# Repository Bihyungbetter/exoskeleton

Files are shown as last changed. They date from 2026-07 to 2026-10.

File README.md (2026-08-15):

# Exoskeleton 

## Overview

Exoskeleton is a powered lower-limb exoskeleton with six actuated joints — hip flexion, hip abduction, and knee flexion per leg. Each joint is driven by a CubeMars AK-series actuator (AK70-10 / AK80-64) commanded over CAN by a Teensy 4.1 running through a custom dual-CAN power distribution board, which supplies six independent motor power outputs. The frame — waist, hip abductors, hip-to-thigh, thigh-to-knee, and knee-to-shank sections — is designed in SolidWorks; the electronics are designed in KiCad.

## Features

- Six actuated joints (hip flexion, hip abduction, knee) via CubeMars AK70-10 / AK80-64 actuators
- Custom power distribution board: XT90 main input, 6× XT30 motor power outputs (one per actuator), 50A MIDI fuse, dump resistor, thermal switch input, and battery voltage sense
- Dual CAN bus (CAN A / CAN B, SN65HVD230 transceivers) for actuator communication
- Teensy 4.1 as the main controller
- Modular frame: waist (left/middle/right), hip abductors, hip-to-waist and hip-to-thigh frames, thigh-to-knee frames, knee-to-shank frames, and hip/knee step-up and step-down joint hardware

## Repository layout

- `SolidWorks Assembly/July 2026/July 2026 Exo Assembly/` — SolidWorks parts and the top-level assembly (`Pitt Exo - Final July 2026 Assembly.SLDASM`)
- `pcb/` — KiCad project for the power distribution / control board (schematic, PCB layout, fabrication outputs)
- `pcb/production/` — BOM, designators, placement data, IPC netlist, and Gerber/drill ZIP for fabrication
- `Digikey Order`, `Exoskeleton-JLCPCB Assembly Order (1).xls` — component and assembly ordering records

## Bill of materials

The authoritative electrical BOM is [`pcb/production/bom.csv`](pcb/production/bom.csv). In summary, the power/control board uses:

- 1 Teensy 4.1 controller
- 2 SN65HVD230 CAN transceivers (CAN A / CAN B)
- 1 XT90 power input and 6 XT30 motor power connectors
- 1 50A MIDI fuse, 1 IRFB4110 MOSFET, dump resistor output, thermal switch input, and battery sense header
- Supporting passives (bulk 680 µF caps, TVS/flyback diodes, 120 Ω CAN bus termination)

The mechanical assembly (SolidWorks) is built from 22 parts, including the waist sections, left/right hip abductors, hip-to-waist and hip-to-thigh frames, thigh-to-knee and knee-to-shank frames, hip/knee step-up and step-down joint hardware, and the AK70-10 / AK80-64 motor body and center mounts.

## Pictures



Exoskeleton



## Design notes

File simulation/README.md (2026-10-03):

# exo-sim

MuJoCo simulation of a person wearing a hip/knee exoskeleton (waist, bilateral
hip abduction and flexion, knee), with a PPO policy that drives the exo motors
while the person walks. The exo model comes from our SolidWorks assembly and
the human model is MyoSuite's MyoLeg from MyoAssist.

## Layout

| path | what |
|---|---|
| `controllers/human_baseline.py` | human side: PD hold on the 8 leg joints, per-joint torque caps, trunk (root) hold |
| `controllers/gait.py` | fixed periodic gait for the human's hips and knees |
| `controllers/exo_assistance.py` | exo side: the only code that writes the 6 motor commands; applies rated torque, slew and cuff limits |
| `controllers/safety.py`, `measurements.py`, `wholebody_allocator.py`, `torso_balance.py`, `balance_margin.py` | sensing, safety supervisor, torque allocation |
| `envs/stepping_env.py` | Gymnasium env (plant + human + exo + reward). Walking uses `exo_action=True, gait_drive=True` |
| `envs/plant_setup.py` | drops the feet onto the floor and lines the exo up with the body at reset |
| `scripts/train_stepping_ppo.py` | PPO trainer (Stable-Baselines3), normally run through `tools/train_watchdog.py` |
| `tools/evaluate_walking.py` | scores policies against the control on held-out seeds |
| `tools/view_policy.py` | plays a policy in the MuJoCo viewer |
| `models/human_exo_direct_ak80abd.xml` | plant used for all results below (exo torque applied straight to the human joints, abduction motors sized as AK80-64) |
| `models/human_exo_direct.xml` | same direct plant with the original AK70-10 abduction motors; `SteppingEnv`'s default |
| `models/human_exo.xml` | the real attachment: exo coupled to the body through five compliant cuffs |
| `models/meshes/` | exo meshes from the CAD (visual and collision) |
| `models/walking_decim5_20260916.zip` | trained policy |
| `models/gait_walk_base.json`, `models/exo_transmission_calibration*.json` | gait parameters, exo transmission calibration |
| `runs/` | train, score and view scripts with matching flags |

## Running it

```powershell
runs\run_view_walking_decim5.cmd            # watch the policy (pass "none" for the control)
runs\score_walking_decim5.cmd               # policy vs control on 48 held-out seeds
runs\run_walking_decim5_20260916.cmd        # retrain; ~2 h on 6 workers, overwrites the policy file
```

Setup: Python 3.11, `pip install -r requirements.txt`, and a clone of
[MyoAssist](https://github.com/neumovelab/myoassist) at `third_party/myoassist`.
Only its MyoLeg model files (`myosuite/simhive/myo_sim`) are used, so it doesn't
need to be pip-installed. The model XMLs have absolute paths in them, but
`tools/model_paths.py` rewrites those relative to wherever the repo lives, so a
fresh clone works once MyoAssist is in place.

## Results so far

48 held-out seeds (40000 to 40047), 12 s episodes, exo control running at 200 Hz:

| | falls | distance | exo share of hip+knee torque |
|---|---|---|---|
| control (fixed assist law, offload 0.6) | 32/48 | 1.82 m | 29% |
| trained policy | 0/48 | 3.72 m | 53% |

Most of the gain is in not falling. Human hip/knee torque only drops about 5%
compared with the control, and under the policy at least one motor is pinned at
its 48 N·m limit about half the time.

## Limitations

These numbers don't transfer to a real person yet, for a few reasons.

The trunk is kept upright by a 100 N·m PD torque applied directly to the root
joint, with no reaction on the rest of the body (about 43 N·m on average under
the policy). Without it the model falls over during the settle phase. Relative
comparisons between arms are fine since every arm gets the same hold, but
absolute survival rates aren't meaningful.

The human is torque driven. The MyoLeg model has 80 muscles but none of them
are used, and the human doesn't adapt to the exo: it's a fixed gait on fixed
PD gains. The ankle is held at neutral by a PD spring, so there's no push-off,
and the exo has no ankle motor.

Everything above is on the direct-drive plant. On the cuff model
(`human_exo.xml`) every seed falls: the cuffs only pass about 6 N·m in total, so
fixing the attachment is a mechanical design problem before it's a control one.

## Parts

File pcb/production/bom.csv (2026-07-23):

Designator | Footprint | Quantity | Value | LCSC Part #
_4, _3, _2, |  | 4
C1, C2, C3, C4 | CP_Radial_D18.0mm_P7.50mm | 4 | 680uF 100V
C5 | C_Disc_D7.5mm_W4.4mm_P5.00mm | 1 | 100nF
C6, C9 | 0805 | 2 | 100nF
C7 | 1206 | 1 | 10uF 25V
C8 | 0805 | 1 | 10nF
D1 | D_SMC | 1 | SMCJ58CA
D2 | SOT-23 | 1 | BAT54S
D3 | D_DO-41_SOD81_P10.16mm_Horizontal | 1 | BZX85C12
D4 | LED_D3.0mm | 1 | CHOP_ACTIVE
D5 | D_SMC | 1 | ES3D
F1 | Fuse_MIDI_BF1-58V_50A_BoltDown_2xM6_P30mm | 1 | BF1 58V MIDI 50A (142.7010.5502)
J11 | AMASS_XT30PW-F_1x02_P2.50mm_Horizontal | 1 | PWR M5
J13 | AMASS_XT30PW-F_1x02_P2.50mm_Horizontal | 1 | PWR M6
J15 | PinHeader_1x02_P2.54mm_Vertical | 1 | TERM2
J16 | PinHeader_1x02_P2.54mm_Vertical | 1 | BATT_SENSE
J17 | AMASS_XT30PW-F_1x02_P2.50mm_Horizontal | 1 | DUMP_RESISTOR
J19 | PinHeader_1x02_P2.54mm_Vertical | 1 | THERMAL_SW
J2 | PinHeader_1x02_P2.54mm_Vertical | 1 | TERM
J3 | AMASS_XT30PW-F_1x02_P2.50mm_Horizontal | 1 | PWR M1
J4 | JST_GH_SM02B-GHS-TB_1x02-1MP_P1.25mm_Horizontal | 1 | CANA
J5 | AMASS_XT30PW-F_1x02_P2.50mm_Horizontal | 1 | PWR M2
J6 | JST_GH_SM02B-GHS-TB_1x02-1MP_P1.25mm_Horizontal | 1 | CANB
J7 | AMASS_XT30PW-F_1x02_P2.50mm_Horizontal | 1 | PWR M3
J9 | AMASS_XT30PW-F_1x02_P2.50mm_Horizontal | 1 | PWR M4
Q1 | SOT-23 | 1 | MMBT3906
Q2 | TO-220-3_Vertical | 1 | IRFB4110
R1, R5 | R_Axial_DIN0207_L6.3mm_D2.5mm_P10.16mm_Horizontal | 2 | 120R
R10, R7 | 0805 | 2 | 4.7K
R11 | 0805 | 1 | 5.1K
R12 | 0805 | 1 | 1K
R13, R16, R17, R2, R20, R6 | 0805 | 6 | 10K
R14 | 0805 | 1 | 1M
R15 | 0805 | 1 | 100
R18, R9 | 0805 | 2 | 100K
R19 | 0805 | 1 | 33K
R3 | R_Axial_DIN0207_L6.3mm_D2.5mm_P10.16mm_Horizontal | 1 | 1K
R8 | R_Axial_Power_L20.0mm_W6.4mm_P25.40mm | 1 | 1K 3W
SW1 | SW_Slide_SPDT_Straight_CK_OS102011MS2Q | 1 | SW_SPDT
U1 | Teensy41 | 1 | Teensy4.1
U2, U4 | SOIC-8_3.9x4.9mm_P1.27mm | 2 | SN65HVD230
U3 | TO-92_Inline | 1 | TL431LP
XT90PWRIN1 | AMASS_XT90PW-M_1x02_P10.90mm_Horizontal | 1 | Conn_01x02_Pin

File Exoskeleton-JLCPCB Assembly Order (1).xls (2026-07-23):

JLCPCB BOM Tool - BOM Matching
BOM name：Exoskeleton-JLCPCB Assembly Order.xlsx |  |  | Download Time：2026-07-23 23:40:37 |  |  |  | * Our matching results are updated in real-time, but stock and prices may change. If it's been over 24 hours, please re-match before placing your order.
PCB Assembled Qty：5 |  |  | Est. Total Price：61.8538
Your BOM |  |  |  |  | Matched Parts |  |  |  |  |  |  | Order Information
Top Designator | Bottom Designator | Comment | Footprint | JLCPCB Part # | Matches | Part # | Manufacturer | Footprint | Description | Category | Warning | JLCPCB Part # | Product link | Lib Type | Qty | Source | Total Price ($)
C1,C2,C3,C4 |  | 680uF100V | Capacitor_THT:CP_Radial_D18.0mm_P7.50mm |  | Select by Customer | EEUFC2A681 | PANASONIC | 插件,D18xL40mm | -55℃~+105℃ 100V 18mm 2.3A@100kHz 36mΩ@100kHz 40mm 5000hrs@105℃ 680uF 7.5mm ±20% 插件,D18xL40mm Aluminum Electrolytic Capacitors - Leaded ROHS | Aluminum Electrolytic Capacitors - Leaded |  | C178686 | https://jlcpcb.com/partdetail/PANASONIC-EEUFC2A681/C178686 | Extended | 20 | 20 JLCPCB | 37.028
C5 |  | 100nF | Capacitor_THT:C_Disc_D7.5mm_W4.4mm_P5.00mm |  | Select by Customer | CT4G-0805-2X1-63V-0.1uF-K | TORCH | 插件,P=5.08mm | 100nF 5.08mm 63V ±10% 插件,P=5.08mm Multilayer Ceramic Capacitors MLCC - Leaded ROHS | Multilayer Ceramic Capacitors MLCC - Leaded |  | C400087 | https://jlcpcb.com/partdetail/TORCH-CT4G_0805_2X1_63V_0_1uFK/C400087 | Extended | 9 | 9 JLCPCB | 0.4968
C6,C9 |  | 100nF | Capacitor_SMD:C_0805_2012Metric |  | Select by System | CC0805KRX7R9BB104 | YAGEO | 0805 | 100nF 50V X7R ±10% 0805 Multilayer Ceramic Capacitors MLCC - SMD/SMT ROHS | Multilayer Ceramic Capacitors MLCC - SMD/SMT |  | C49678 | https://jlcpcb.com/partdetail/YAGEO-CC0805KRX7R9BB104/C49678 | Basic | 20 | 20 JLCPCB | 0.642
C7 |  | 10uF25V | Capacitor_SMD:C_1206_3216Metric |  | Select by System | CL31A106KBHNNNE | Samsung Electro-Mechanics | 1206 | 10uF 50V X5R ±10% 1206 Multilayer Ceramic Capacitors MLCC - SMD/SMT ROHS | Multilayer Ceramic Capacitors MLCC - SMD/SMT |  | C13585 | https://jlcpcb.com/partdetail/14236-CL31A106KBHNNNE/C13585 | Basic | 9 | 9 JLCPCB | 4.0725
C8 |  | 10nF | Capacitor_SMD:C_0805_2012Metric |  | Select by System | CL21B103KBANNNC | Samsung Electro-Mechanics | 0805 | 10nF 50V X7R ±10% 0805 Multilayer Ceramic Capacitors MLCC - SMD/SMT ROHS | Multilayer Ceramic Capacitors MLCC - SMD/SMT |  | C1710 | https://jlcpcb.com/partdetail/2062-CL21B103KBANNNC/C1710 | Basic | 20 | 20 JLCPCB | 0.378
D1 |  | SMCJ58CA | Diode_SMD:D_SMC |  | Select by System | SMCJ58CA | DOWO | SMC(DO-214AB) | -55℃~+150℃ 1.5kW@10/1000us 16.03A 1uA 58V 64.4V 93.6V Bidirectional IEC 61000-4-2 TVS SMC(DO-214AB) ESD and Surge Protection (TVS/ESD) ROHS | ESD And Surge Protection (TVS/ESD) |  | C2887185 | https://jlcpcb.com/partdetail/DOWO-SMCJ58CA/C2887185 | Extended | 6 | 6 JLCPCB | 0.591
D2 |  | BAT54S | Package_TO_SOT_SMD:SOT-23 |  | Select by System | BAT54S | hongjiacheng | SOT-23 | 1 Pair Series Connection 200mA 2uA@30V 30V 400mV@10mA 600mA SOT-23 Schottky Diodes ROHS | Schottky Diodes |  | C7420333 | https://jlcpcb.com/partdetail/hongjiacheng-BAT54S/C7420333 | Extended | 10 | 10 JLCPCB | 0.151
D3 |  | BZX85C12 | Diode_THT:D_DO-41_SOD81_P10.16mm_Horizontal |  | Select by System | BZX85C12 | onsemi | DO-41 | -65℃~+200℃ 1 Independent 11.4V~12.7V 12V 1W 350Ω 500nA@8.4V 9Ω DO-41 Zener Diodes ROHS | Zener Diodes |  | C890279 | https://jlcpcb.com/partdetail/onsemi-BZX85C12/C890279 | Extended | 7 | 7 JLCPCB | 0.7518
D4 |  | CHOP_ACTIVE | LED_THT:LED_D3.0mm |  | Select by Customer | 204-10SDRD/S530-A3-L | Everlight Elec | 插件,D=3mm | -40℃~+85℃ 1.7V~2.4V 20mA 3mm Round Lens 40mcd~80mcd 50° 639nm 650nm Discrete Diode Frosted Red Lens Red 插件,D=3mm LED Indication - Discrete ROHS | LED Indication - Discrete |  | C84774 | https://jlcpcb.com/partdetail/EverlightElec-204_10SDRD_S530_A3L/C84774 | Extended | 7 | 7 JLCPCB | 0.2352
D5 |  | ES3D | Diode_SMD:D_SMC |  | Select by System | ES3D | YFW | SMB | -55℃~+150℃ 1 Independent 200V 35ns 3A 5uA@200V 90A 950mV@3A SMB Fast Recovery / High Efficiency Diodes ROHS | Fast Recovery / High Efficiency Diodes |  | C2898336 | https://jlcpcb.com/partdetail/YFW-ES3D/C2898336 | Extended | 9 | 9 JLCPCB | 0.3501
J4 |  | CANA | Connector_JST:JST_GH_SM02B-GHS-TB_1x02-1MP_P1.25mm_Horizontal |  | Select by Customer | SM02B-GHS-TB(LF)(SN) | JST | SMD,P=1.25mm,卧贴 | -25℃~+85℃ 1 1.25mm 1A 1x2P 2 2P 4.13mm 4.25mm 5.75mm 50V Auxiliary Solder Pin GH PA9T Phosphor bronze Surface Mount, Right Angle Tin UL94V-0 White SMD,P=1.25mm,卧贴 Wire To Board Connector ROHS | Wire To Board Connector | 1.Multiple lines in the BOM have been matched to the same part. Please check if the matching is correct. ; | C189893 | https://jlcpcb.com/partdetail/JST-SM02B_GHS_TB_LF_SN/C189893 | Extended | 12 | 12 JLCPCB | 2.298
J6 |  | CANB | Connector_JST:JST_GH_SM02B-GHS-TB_1x02-1MP_P1.25mm_Horizontal |  | Select by Customer | SM02B-GHS-TB(LF)(SN) | JST | SMD,P=1.25mm,卧贴 | -25℃~+85℃ 1 1.25mm 1A 1x2P 2 2P 4.13mm 4.25mm 5.75mm 50V Auxiliary Solder Pin GH PA9T Phosphor bronze Surface Mount, Right Angle Tin UL94V-0 White SMD,P=1.25mm,卧贴 Wire To Board Connector ROHS | Wire To Board Connector | 1.Multiple lines in the BOM have been matched to the same part. Please check if the matching is correct. ; | C189893 | https://jlcpcb.com/partdetail/JST-SM02B_GHS_TB_LF_SN/C189893 | Extended | 12 | 12 JLCPCB | 2.298
Q1 |  | MMBT3906 | Package_TO_SOT_SMD:SOT-23 |  | Select by System | MMBT3906 | hongjiacheng | SOT-23 | -55℃~+150℃ 1 PNP 100 100nA 200mA 200mW 300MHz 300mV 40V 5V PNP SOT-23 Bipolar (BJT) ROHS | Bipolar (BJT) |  | C7420354 | https://jlcpcb.com/partdetail/hongjiacheng-MMBT3906/C7420354 | Extended | 10 | 10 JLCPCB | 0.124
Q2 |  | IRFB4110 | Package_TO_SOT_THT:TO-220-3_Vertical |  | Select by System | IRFB4110 | Minos | TO-220 | -55℃~+175℃ 1 N-channel 100V 108nC@10V 180A 210pF 211W 3V 5mΩ@10V 6.6nF TO-220 MOSFETs ROHS | MOSFETs |  | C19189954 | https://jlcpcb.com/partdetail/Minos-IRFB4110/C19189954 | Extended | 5 | 5 JLCPCB | 4.496
R2,R6,R13,R16,R17,R20 |  | 10K | Resistor_SMD:R_0805_2012Metric |  | Unconfirmed | 0805W8F1002T5E | UNI-ROYAL(Uniroyal Elec) | 0805 | -55℃~+155℃ 10kΩ 125mW 150V Thick Film Resistor ±1% ±100ppm/℃ 0805 Chip Resistor - Surface Mount ROHS | Chip Resistor - Surface Mount | 1.The comment (0805W8F1002T5E) of this part does not match the one (10K) provided in your BOM. Please confirm; | C17414 | https://jlcpcb.com/partdetail/18102-0805W8F1002T5E/C17414 | Basic | 40 | 40 JLCPCB | 0.204
R7,R10 |  | 4.7K | Resistor_SMD:R_0805_2012Metric |  | Unconfirmed | 0805W8F4701T5E | UNI-ROYAL(Uniroyal Elec) | 0805 | -55℃~+155℃ 125mW 150V 4.7kΩ Thick Film Resistor ±1% ±100ppm/℃ 0805 Chip Resistor - Surface Mount ROHS | Chip Resistor - Surface Mount | 1.The comment (0805W8F4701T5E) of this part does not match the one (4.7K) provided in your BOM. Please confirm; | C17673 | https://jlcpcb.com/partdetail/18361-0805W8F4701T5E/C17673 | Basic | 20 | 20 JLCPCB | 0.218
R9,R18 |  | 100K | Resistor_SMD:R_0805_2012Metric |  | Unconfirmed | 0805W8F1003T5E | UNI-ROYAL(Uniroyal Elec) | 0805 | -55℃~+155℃ 100kΩ 125mW 150V Thick Film Resistor ±1% ±100ppm/℃ 0805 Chip Resistor - Surface Mount ROHS | Chip Resistor - Surface Mount | 1.The comment (0805W8F1003T5E) of this part does not match the one (100K) provided in your BOM. Please confirm; | C149504 | https://jlcpcb.com/partdetail/160838-0805W8F1003T5E/C149504 | Basic | 20 | 20 JLCPCB | 0.206
R11 |  | 5.1K | Resistor_SMD:R_0805_2012Metric |  | Unconfirmed | 0805W8F5101T5E | UNI-ROYAL(Uniroyal Elec) | 0805 | -55℃~+155℃ 125mW 150V 5.1kΩ Thick Film Resistor ±1% ±100ppm/℃ 0805 Chip Resistor - Surface Mount ROHS | Chip Resistor - Surface Mount | 1.The comment (0805W8F5101T5E) of this part does not match the one (5.1K) provided in your BOM. Please confirm; | C27834 | https://jlcpcb.com/partdetail/28584-0805W8F5101T5E/C27834 | Basic | 20 | 20 JLCPCB | 0.27
R12 |  | 1K | Resistor_SMD:R_0805_2012Metric |  | Unconfirmed | 0805W8F1001T5E | UNI-ROYAL(Uniroyal Elec) | 0805 | -55℃~+155℃ 125mW 150V 1kΩ Thick Film Resistor ±1% ±100ppm/℃ 0805 Chip Resistor - Surface Mount ROHS | Chip Resistor - Surface Mount | 1.The comment (0805W8F1001T5E) of this part does not match the one (1K) provided in your BOM. Please confirm; | C17513 | https://jlcpcb.com/partdetail/18201-0805W8F1001T5E/C17513 | Basic | 20 | 20 JLCPCB | 0.098
R14 |  | 1M | Resistor_SMD:R_0805_2012Metric |  | Unconfirmed | 0805W8F1004T5E | UNI-ROYAL(Uniroyal Elec) | 0805 | -55℃~+155℃ 125mW 150V 1MΩ Thick Film Resistor ±1% ±100ppm/℃ 0805 Chip Resistor - Surface Mount ROHS | Chip Resistor - Surface Mount | 1.The comment (0805W8F1004T5E) of this part does not match the one (1M) provided in your BOM. Please confirm; | C17514 | https://jlcpcb.com/partdetail/18202-0805W8F1004T5E/C17514 | Basic | 20 | 20 JLCPCB | 0.126
R15 |  | 100 | Resistor_SMD:R_0805_2012Metric |  | Unconfirmed | 0805W8F1000T5E | UNI-ROYAL(Uniroyal Elec) | 0805 | -55℃~+155℃ 100Ω 125mW 150V Thick Film Resistor ±1% ±100ppm/℃ 0805 Chip Resistor - Surface Mount ROHS | Chip Resistor - Surface Mount | 1.The comment (0805W8F1000T5E) of this part does not match the one (100) provided in your BOM. Please confirm; | C17408 | https://jlcpcb.com/partdetail/18096-0805W8F1000T5E/C17408 | Basic | 20 | 20 JLCPCB | 0.206
R19 |  | 33K | Resistor_SMD:R_0805_2012Metric |  | Unconfirmed | 0805W8F3302T5E | UNI-ROYAL(Uniroyal Elec) | 0805 | -55℃~+155℃ 125mW 150V 33kΩ Thick Film Resistor ±1% ±100ppm/℃ 0805 Chip Resistor - Surface Mount ROHS | Chip Resistor - Surface Mount | 1.The comment (0805W8F3302T5E) of this part does not match the one (33K) provided in your BOM. Please confirm; | C17633 | https://jlcpcb.com/partdetail/18321-0805W8F3302T5E/C17633 | Basic | 20 | 20 JLCPCB | 0.086
SW1 |  | SW_SPDT | Button_Switch_THT:SW_Slide_SPDT_Straight_CK_OS102011MS2Q |  | Select by Customer | KH-SS12D07-VG2H | Shenzhen Kinghelm Elec | 插件 | 4.5mm 6.7mm 8.6mm Black PC Pin Rectangular Columnar SPDT Through Hole Plugin Slide Switches ROHS | Slide Switches |  | C5274457 | https://jlcpcb.com/partdetail/6005330-KH_SS12D07VG2H/C5274457 | Extended | 5 | 5 JLCPCB | 0.28
U2,U4 |  | SN65HVD230 | Package_SO:SOIC-8_3.9x4.9mm_P1.27mm |  | Unconfirmed | SN65HVD230DR | Texas Instruments | SOIC-8 | -40℃~+85℃ 17mA 1Mbps 370uA 3V~3.6V CAN Transceiver SOIC-8 CAN Transceivers ROHS | CAN Transceivers | 1.The comment (SN65HVD230DR) of this part does not match the one (SN65HVD230) provided in your BOM. Please confirm; | C12084 | https://jlcpcb.com/partdetail/TexasInstruments-SN65HVD230DR/C12084 | Extended | 10 | 10 JLCPCB | 5.833
U3 |  | TL431LP | Package_TO_SOT_THT:TO-92_Inline |  | Select by Customer | TL431(0.5%) | UMW(Youtai Semiconductor Co., Ltd.) | TO-92 | -40℃~+85℃ 100mA 2.495V~36V 500uA 50ppm/℃ Adjustable Parallel ±0.5% TO-92 Voltage Reference ROHS | Voltage Reference |  | C351447 | https://jlcpcb.com/partdetail/327399-TL431_0_5/C351447 | Extended | 8 | 8 JLCPCB | 0.4144
F1 |  | BF158VMIDI50A(142.7010.5502) | Library:Fuse_MIDI_BF1-58V_50A_BoltDown_2xM6_P30mm |  | No matches | No Part Selected
J2 |  | TERM | Connector_PinHeader_2.54mm:PinHeader_1x02_P2.54mm_Vertical |  | Select by Customer |  |  |  |  |  |  |  |  |  | 0 |  | 0
J3 |  | PWRM1 | Connector_AMASS:AMASS_XT30PW-F_1x02_P2.50mm_Horizontal |  | No matches | No Part Selected
J5 |  | PWRM2 | Connector_AMASS:AMASS_XT30PW-F_1x02_P2.50mm_Horizontal |  | No matches | No Part Selected
J7 |  | PWRM3 | Connector_AMASS:AMASS_XT30PW-F_1x02_P2.50mm_Horizontal |  | No matches | No Part Selected
J9 |  | PWRM4 | Connector_AMASS:AMASS_XT30PW-F_1x02_P2.50mm_Horizontal |  | No matches | No Part Selected
J11 |  | PWRM5 | Connector_AMASS:AMASS_XT30PW-F_1x02_P2.50mm_Horizontal |  | No matches | No Part Selected
J13 |  | PWRM6 | Connector_AMASS:AMASS_XT30PW-F_1x02_P2.50mm_Horizontal |  | No matches | No Part Selected
J15 |  | TERM2 | Connector_PinHeader_2.54mm:PinHeader_1x02_P2.54mm_Vertical |  | Select by Customer |  |  |  |  |  |  |  |  |  | 0 |  | 0
J16 |  | BATT_SENSE | Connector_PinHeader_2.54mm:PinHeader_1x02_P2.54mm_Vertical |  | Select by Customer |  |  |  |  |  |  |  |  |  | 0 |  | 0
J17 |  | DUMP_RESISTOR | Connector_AMASS:AMASS_XT30PW-F_1x02_P2.50mm_Horizontal |  | No matches | No Part Selected
J19 |  | THERMAL_SW | Connector_PinHeader_2.54mm:PinHeader_1x02_P2.54mm_Vertical |  | Select by Customer |  |  |  |  |  |  |  |  |  | 0 |  | 0
R1,R5 |  | 120R | Resistor_THT:R_Axial_DIN0207_L6.3mm_D2.5mm_P10.16mm_Horizontal |  | No matches | No Part Selected
R3 |  | 1K | Resistor_THT:R_Axial_DIN0207_L6.3mm_D2.5mm_P10.16mm_Horizontal |  | No matches | No Part Selected
R8 |  | 1K3W | Resistor_THT:R_Axial_Power_L20.0mm_W6.4mm_P25.40mm |  | No matches | No Part Selected
U1 |  | Teensy4.1 | teensy:Teensy41 |  | No matches | No Part Selected
XT90PWRIN1 |  | Conn_01x02_Pin | Connector_AMASS:AMASS_XT90PW-M_1x02_P10.90mm_Horizontal |  | No matches | No Part Selected

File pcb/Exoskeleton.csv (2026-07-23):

Reference | Qty | Value | DNP | Exclude from BOM | Exclude from Board | Footprint | Datasheet
C1,C2,C3,C4 | 4 | 680uF 100V |  |  |  | Capacitor_THT:CP_Radial_D18.0mm_P7.50mm
C5 | 1 | 100nF |  |  |  | Capacitor_THT:C_Disc_D7.5mm_W4.4mm_P5.00mm
C6,C9 | 2 | 100nF |  |  |  | Capacitor_SMD:C_0805_2012Metric
C7 | 1 | 10uF 25V |  |  |  | Capacitor_SMD:C_1206_3216Metric
C8 | 1 | 10nF |  |  |  | Capacitor_SMD:C_0805_2012Metric
D1 | 1 | SMCJ58CA |  |  |  | Diode_SMD:D_SMC
D2 | 1 | BAT54S |  |  |  | Package_TO_SOT_SMD:SOT-23 | https://www.diodes.com/assets/Datasheets/ds11005.pdf
D3 | 1 | BZX85C12 |  |  |  | Diode_THT:D_DO-41_SOD81_P10.16mm_Horizontal
D4 | 1 | CHOP_ACTIVE |  |  |  | LED_THT:LED_D3.0mm
D5 | 1 | ES3D |  |  |  | Diode_SMD:D_SMC
F1 | 1 | BF1 58V MIDI 50A (142.7010.5502) |  |  |  | Library:Fuse_MIDI_BF1-58V_50A_BoltDown_2xM6_P30mm
J2 | 1 | TERM |  |  |  | Connector_PinHeader_2.54mm:PinHeader_1x02_P2.54mm_Vertical
J3 | 1 | PWR M1 |  |  |  | Connector_AMASS:AMASS_XT30PW-F_1x02_P2.50mm_Horizontal
J4 | 1 | CANA |  |  |  | Connector_JST:JST_GH_SM02B-GHS-TB_1x02-1MP_P1.25mm_Horizontal
J5 | 1 | PWR M2 |  |  |  | Connector_AMASS:AMASS_XT30PW-F_1x02_P2.50mm_Horizontal
J6 | 1 | CANB |  |  |  | Connector_JST:JST_GH_SM02B-GHS-TB_1x02-1MP_P1.25mm_Horizontal
J7 | 1 | PWR M3 |  |  |  | Connector_AMASS:AMASS_XT30PW-F_1x02_P2.50mm_Horizontal
J9 | 1 | PWR M4 |  |  |  | Connector_AMASS:AMASS_XT30PW-F_1x02_P2.50mm_Horizontal
J11 | 1 | PWR M5 |  |  |  | Connector_AMASS:AMASS_XT30PW-F_1x02_P2.50mm_Horizontal
J13 | 1 | PWR M6 |  |  |  | Connector_AMASS:AMASS_XT30PW-F_1x02_P2.50mm_Horizontal
J15 | 1 | TERM2 |  |  |  | Connector_PinHeader_2.54mm:PinHeader_1x02_P2.54mm_Vertical
J16 | 1 | BATT_SENSE |  |  |  | Connector_PinHeader_2.54mm:PinHeader_1x02_P2.54mm_Vertical
J17 | 1 | DUMP_RESISTOR |  |  |  | Connector_AMASS:AMASS_XT30PW-F_1x02_P2.50mm_Horizontal
J19 | 1 | THERMAL_SW |  |  |  | Connector_PinHeader_2.54mm:PinHeader_1x02_P2.54mm_Vertical
Q1 | 1 | MMBT3906 |  |  |  | Package_TO_SOT_SMD:SOT-23
Q2 | 1 | IRFB4110 |  |  |  | Package_TO_SOT_THT:TO-220-3_Vertical
R1,R5 | 2 | 120R |  |  |  | Resistor_THT:R_Axial_DIN0207_L6.3mm_D2.5mm_P10.16mm_Horizontal
R2,R6,R13,R16,R17,R20 | 6 | 10K |  |  |  | Resistor_SMD:R_0805_2012Metric
R3 | 1 | 1K |  |  |  | Resistor_THT:R_Axial_DIN0207_L6.3mm_D2.5mm_P10.16mm_Horizontal
R7,R10 | 2 | 4.7K |  |  |  | Resistor_SMD:R_0805_2012Metric
R8 | 1 | 1K 3W |  |  |  | Resistor_THT:R_Axial_Power_L20.0mm_W6.4mm_P25.40mm
R9,R18 | 2 | 100K |  |  |  | Resistor_SMD:R_0805_2012Metric
R11 | 1 | 5.1K |  |  |  | Resistor_SMD:R_0805_2012Metric
R12 | 1 | 1K |  |  |  | Resistor_SMD:R_0805_2012Metric
R14 | 1 | 1M |  |  |  | Resistor_SMD:R_0805_2012Metric
R15 | 1 | 100 |  |  |  | Resistor_SMD:R_0805_2012Metric
R19 | 1 | 33K |  |  |  | Resistor_SMD:R_0805_2012Metric
SW1 | 1 | SW_SPDT |  |  |  | Button_Switch_THT:SW_Slide_SPDT_Straight_CK_OS102011MS2Q
U1 | 1 | Teensy4.1 |  |  |  | teensy:Teensy41
U2,U4 | 2 | SN65HVD230 |  |  |  | Package_SO:SOIC-8_3.9x4.9mm_P1.27mm | http://www.ti.com/lit/ds/symlink/sn65hvd230.pdf
U3 | 1 | TL431LP |  |  |  | Package_TO_SOT_THT:TO-92_Inline | http://www.ti.com/lit/ds/symlink/tl431.pdf
XT90PWRIN1 | 1 | Conn_01x02_Pin |  |  |  | Connector_AMASS:AMASS_XT90PW-M_1x02_P10.90mm_Horizontal

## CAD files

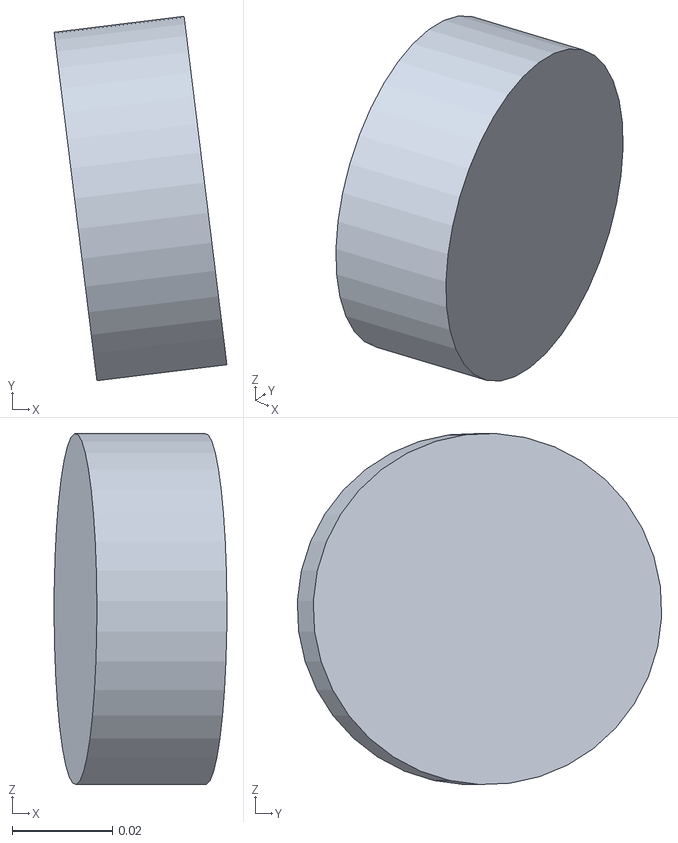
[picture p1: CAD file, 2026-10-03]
simulation/models/meshes/collision/16_Hip_Stepdown_06112026_hull00.obj
0.0344 x 0.0726 x 0.0699

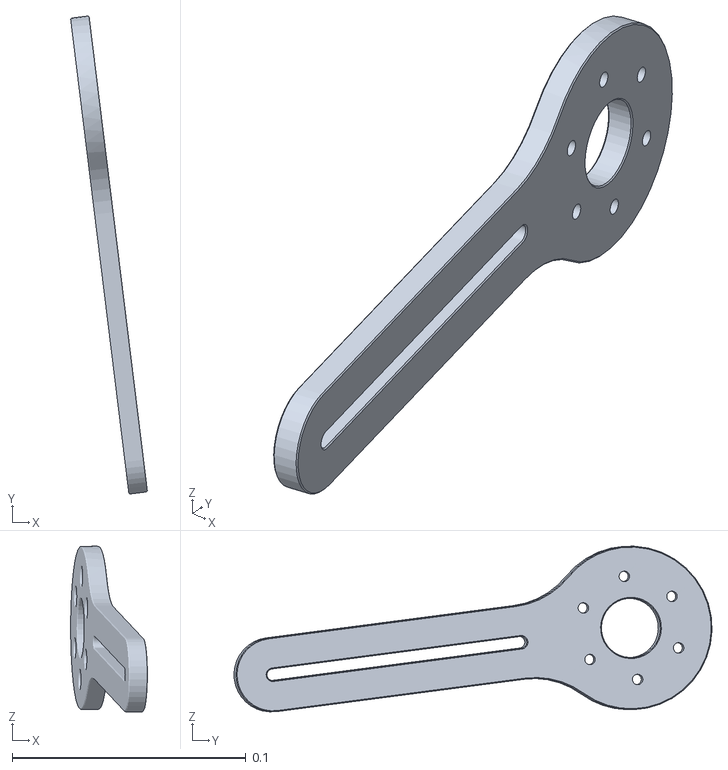
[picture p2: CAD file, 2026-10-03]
simulation/models/meshes/visual/14_Hip_to_Thigh_Frame_05212026.obj
0.0329 x 0.205 x 0.0709

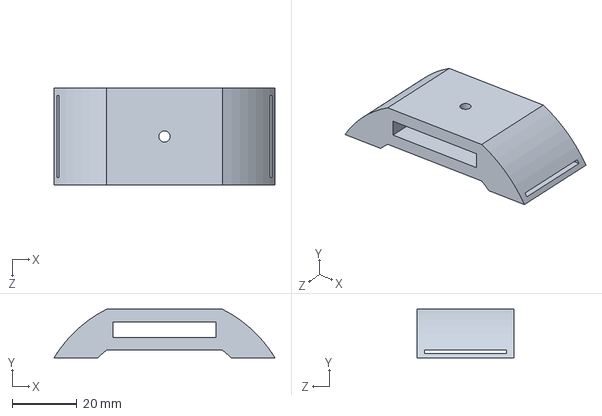
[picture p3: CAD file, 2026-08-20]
SolidWorks Assembly/July 2026/July 2026 Exo Assembly/Strap Mount.SLDPRT
68.3 x 15.0 x 30.0 mm

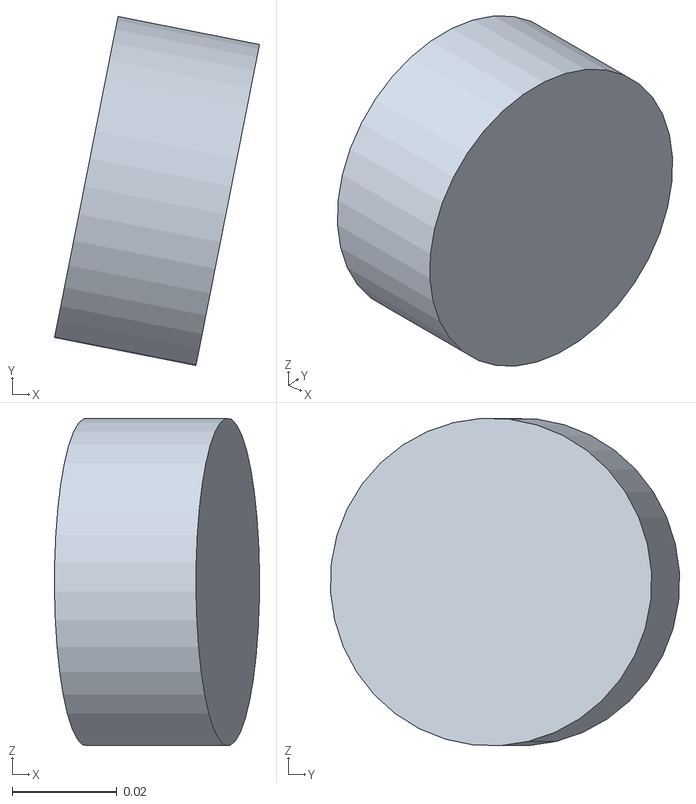
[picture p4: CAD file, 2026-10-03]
simulation/models/meshes/collision/18_Knee_Stepdown_06112026_hull00.obj
0.0391 x 0.0665 x 0.0624

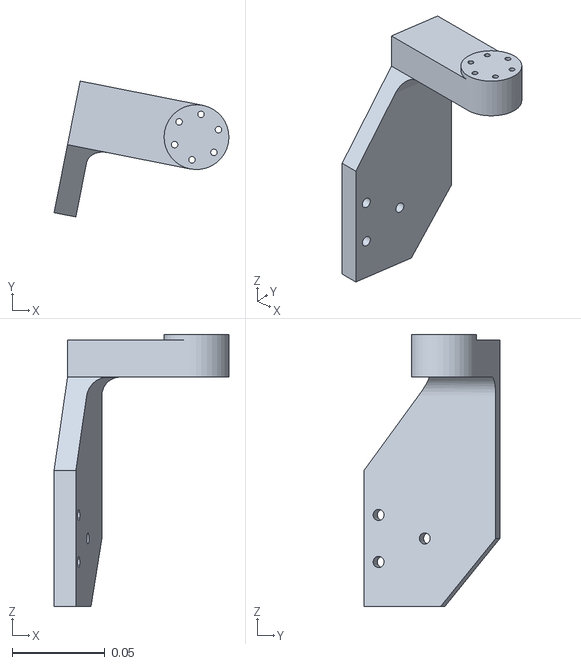
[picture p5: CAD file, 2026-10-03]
simulation/models/meshes/visual/03_Left_Hip_Abductor_07032026.obj
0.0944 x 0.0733 x 0.147

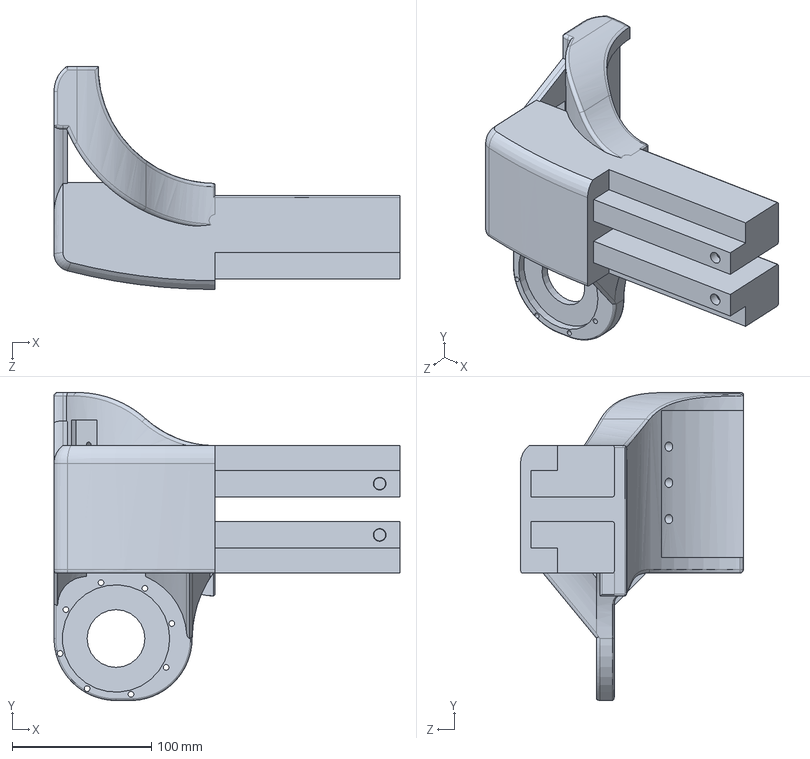
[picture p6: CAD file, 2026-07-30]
SolidWorks Assembly/July 2026/July 2026 Exo Assembly/Right Waist 07212026.SLDPRT
248.3 x 221.0 x 160.0 mm

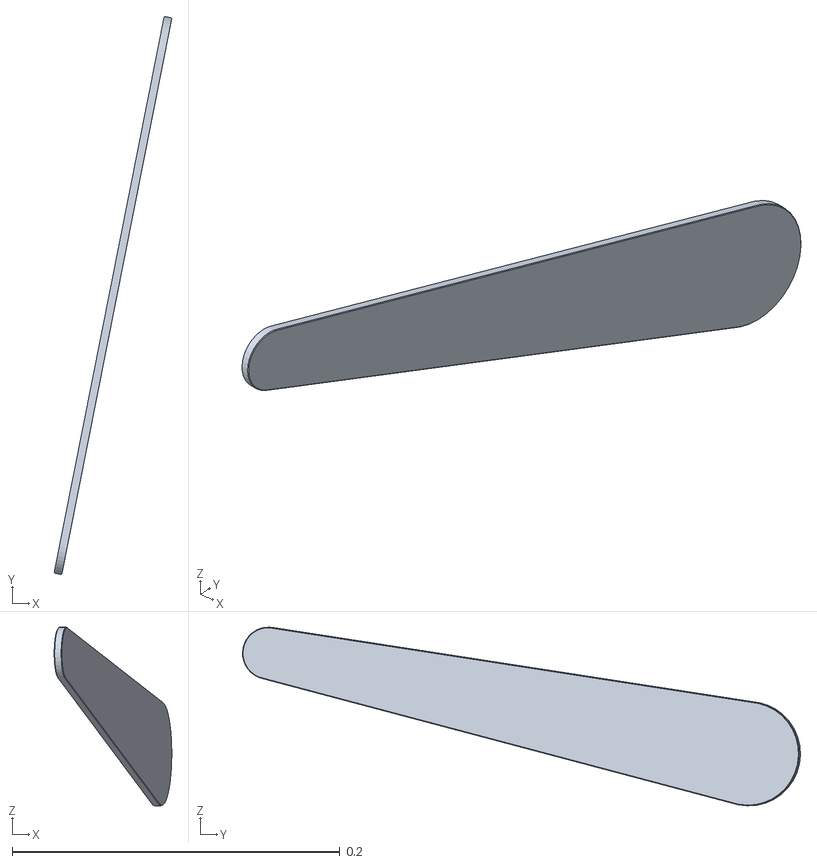
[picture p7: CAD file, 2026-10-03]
simulation/models/meshes/collision/26_Knee_to_Shank_Frame_05212026_hull00.obj
0.0718 x 0.34 x 0.109

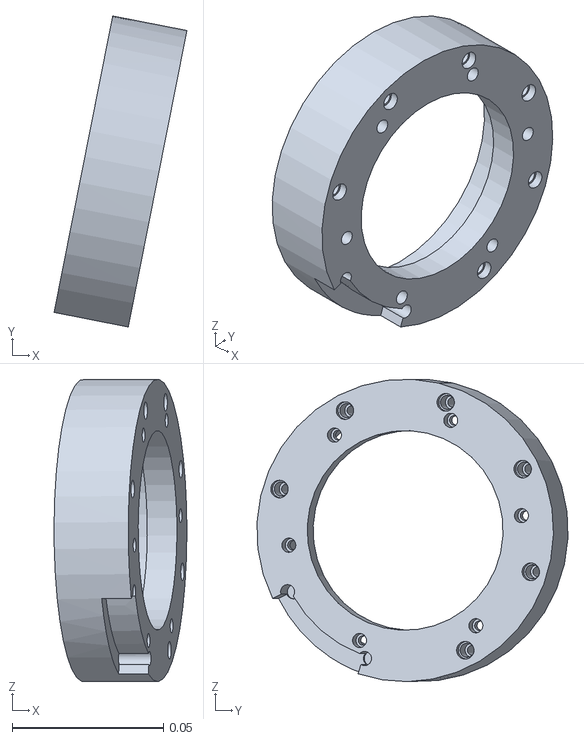
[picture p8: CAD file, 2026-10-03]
simulation/models/meshes/visual/19_Knee_Stepup_Left_06112026.obj
0.0439 x 0.103 x 0.0999

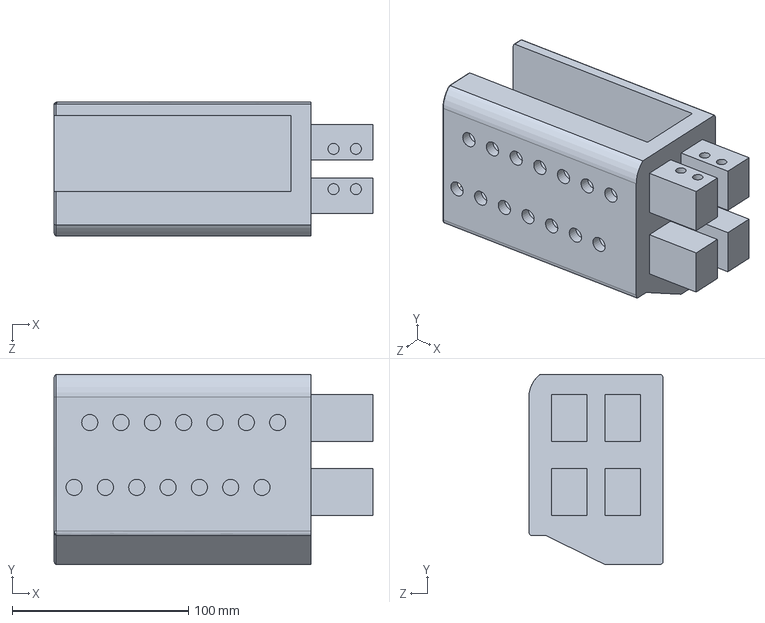
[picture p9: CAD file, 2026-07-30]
SolidWorks Assembly/July 2026/July 2026 Exo Assembly/Middle Waist 07212026.SLDPRT
181.2 x 108.0 x 76.2 mm

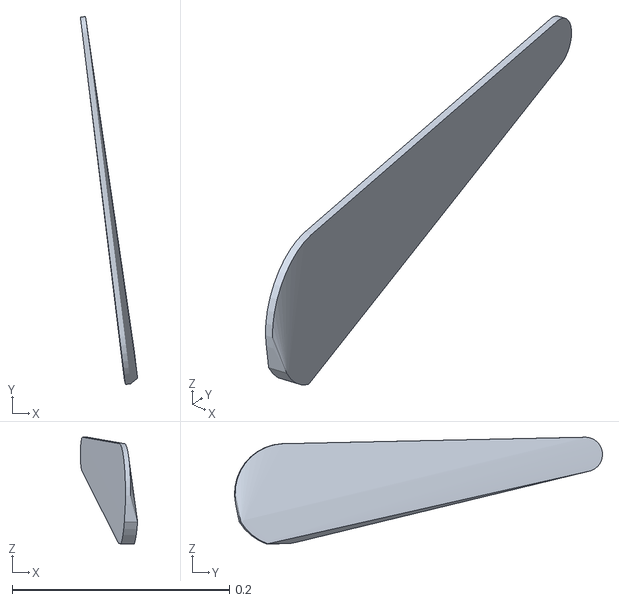
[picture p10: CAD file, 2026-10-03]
simulation/models/meshes/collision/23_Thigh_to_Knee_Frame_Right_05212026_hull00.obj
0.0527 x 0.339 x 0.0981

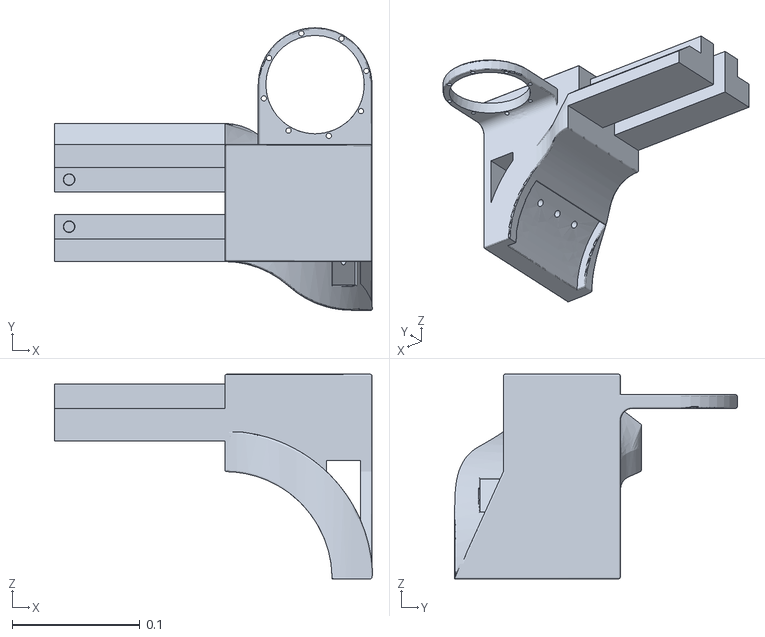
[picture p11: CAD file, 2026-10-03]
simulation/models/meshes/visual/02_Right_Waist_07032026.obj
0.249 x 0.221 x 0.16

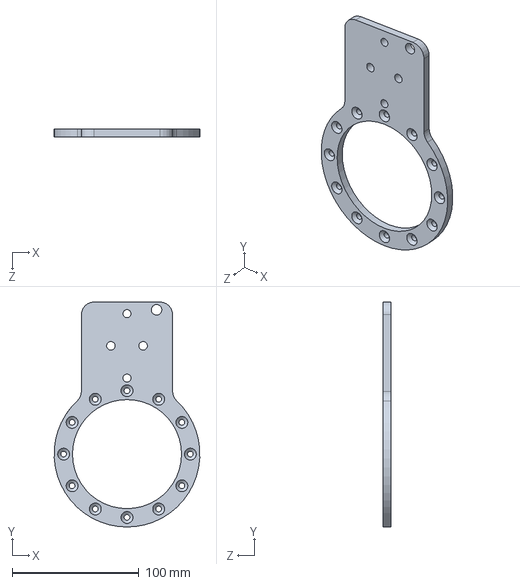
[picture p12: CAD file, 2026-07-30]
SolidWorks Assembly/July 2026/July 2026 Exo Assembly/Hip_to_Waist_Frame_num1_05212026.SLDPRT
114.8 x 177.5 x 6.00 mm

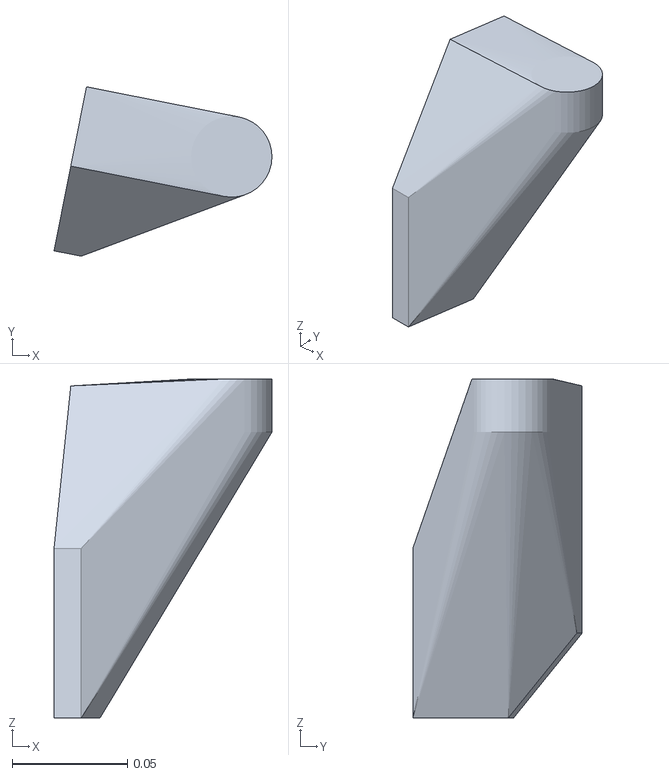
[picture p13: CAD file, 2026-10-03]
simulation/models/meshes/collision/03_Left_Hip_Abductor_07032026_hull00.obj
0.0944 x 0.0733 x 0.147

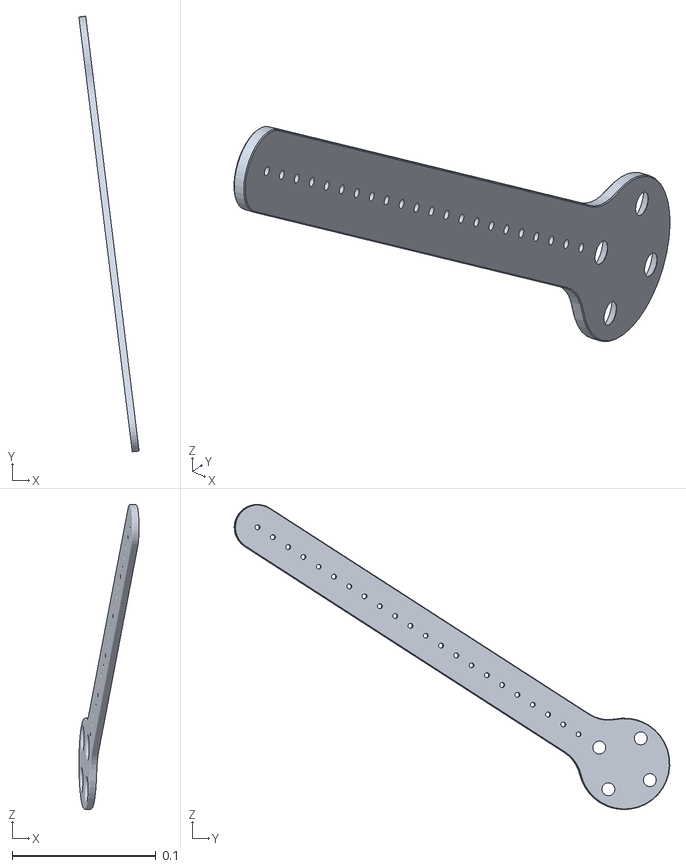
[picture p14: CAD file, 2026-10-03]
simulation/models/meshes/visual/22_Knee_to_Shank_Frame_05212026.obj
0.0418 x 0.303 x 0.212

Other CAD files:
SolidWorks Assembly/July 2026/July 2026 Exo Assembly/Pitt Exo - Final July 2026 Assembly.SLDASM
SolidWorks Assembly/July 2026/July 2026 Exo Assembly/ak70-10 Motor Center.SLDPRT
simulation/models/meshes/collision/24_Thigh_to_Knee_Frame_Left_06112026_hull00.obj
simulation/models/meshes/visual/01_Middle_Waist_Part_07032026.obj
SolidWorks Assembly/July 2026/July 2026 Exo Assembly/Hip_Stepdown_06112026.SLDPRT
SolidWorks Assembly/July 2026/July 2026 Exo Assembly/Hip_Stepup_06112026.SLDPRT
SolidWorks Assembly/July 2026/July 2026 Exo Assembly/Hip_to_Thigh_Frame_05212026.SLDPRT
SolidWorks Assembly/July 2026/July 2026 Exo Assembly/Hip_to_Waist_Frame_num2_05212026.SLDPRT
SolidWorks Assembly/July 2026/July 2026 Exo Assembly/Knee Constraint.SLDPRT
SolidWorks Assembly/July 2026/July 2026 Exo Assembly/Knee_Stepdown_06112026.SLDPRT
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

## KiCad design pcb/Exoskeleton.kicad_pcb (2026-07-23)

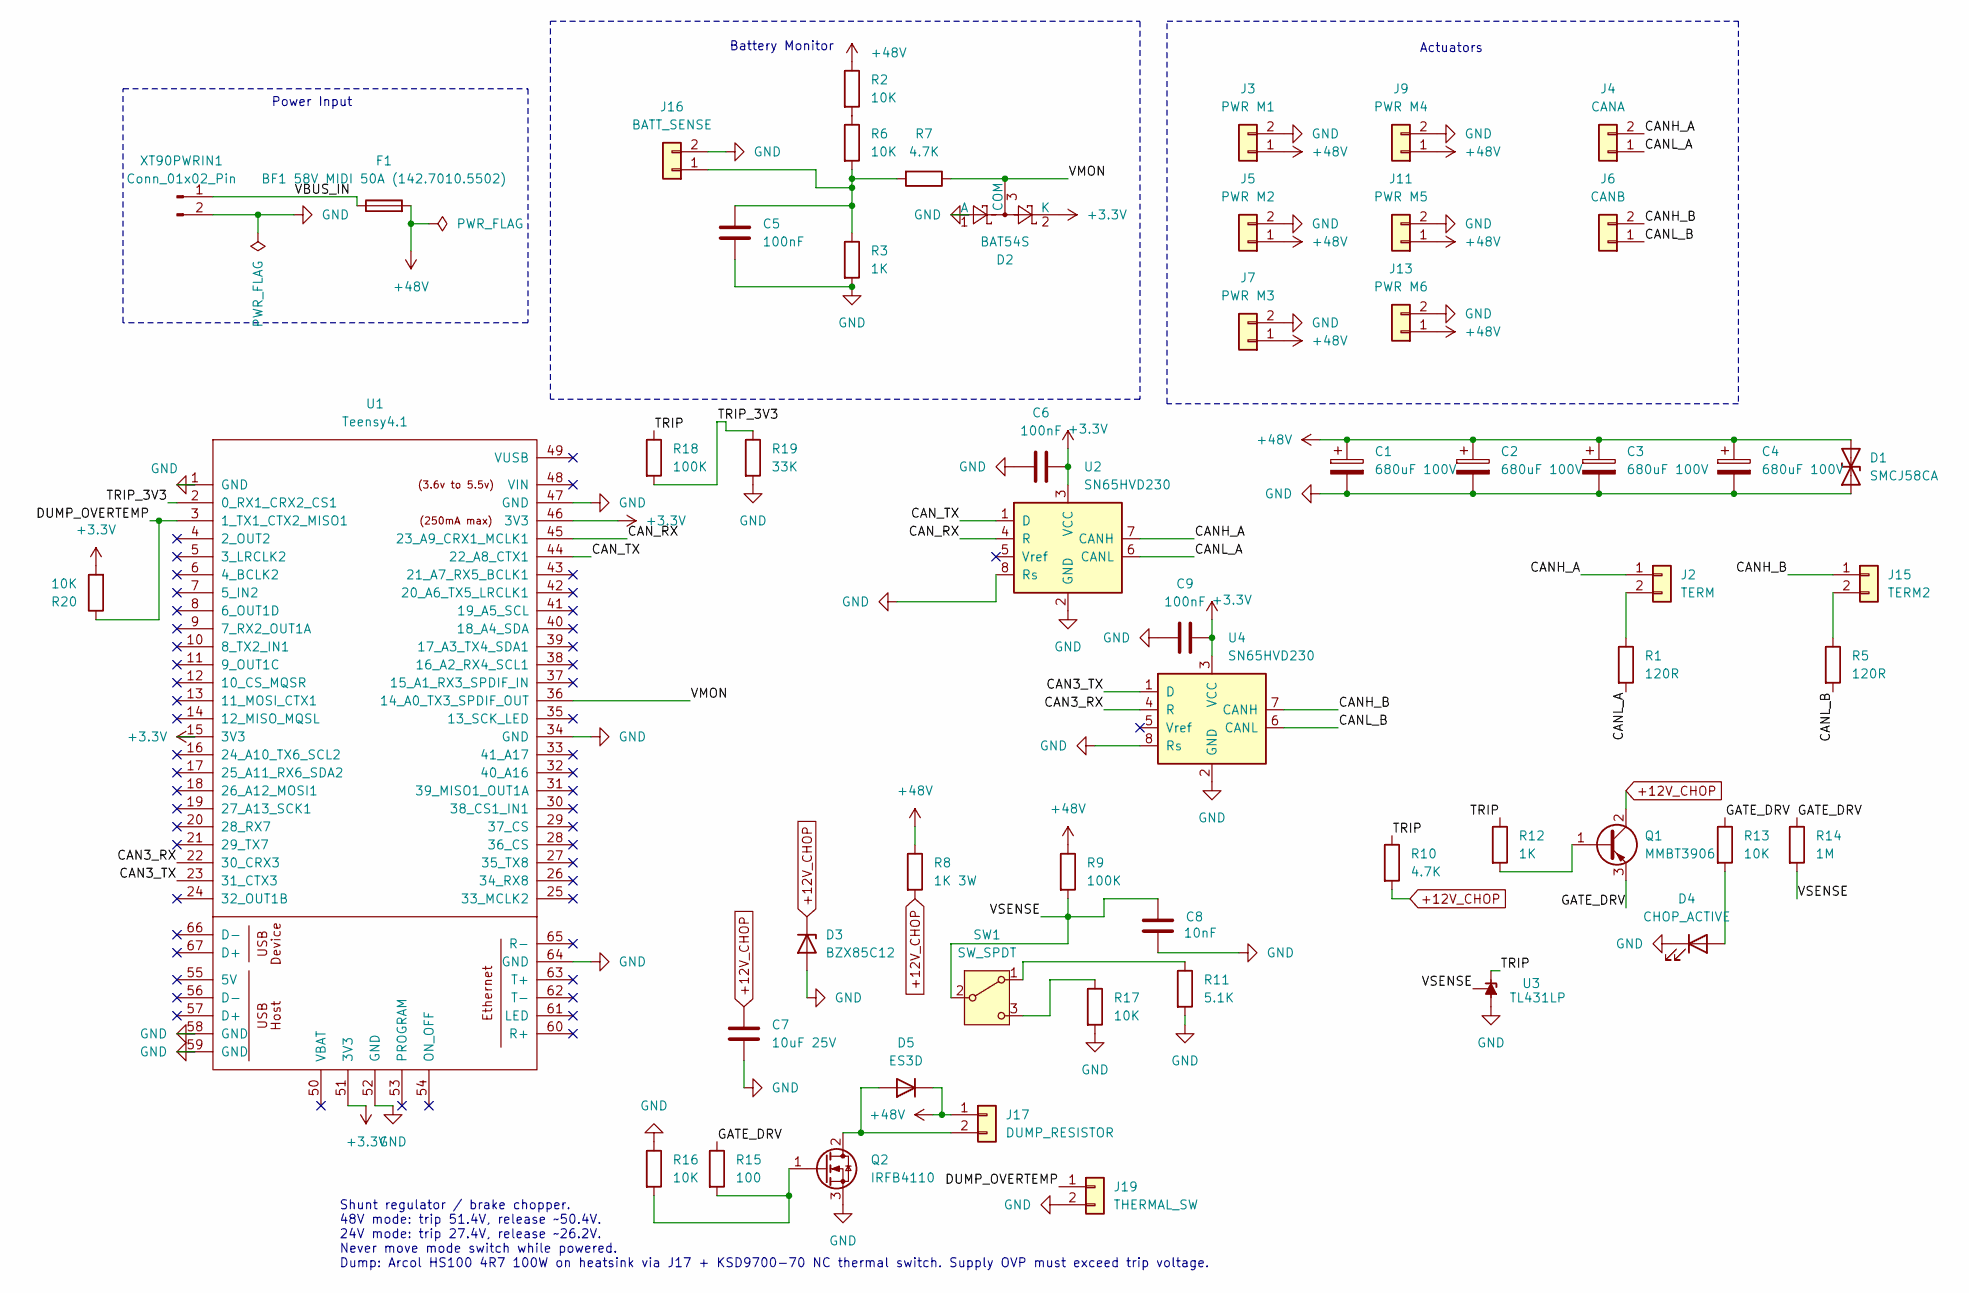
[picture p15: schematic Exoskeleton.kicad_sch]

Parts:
C1, C2, C3, C4: 680uF 100V; CP_Radial_D18.0mm_P7.50mm
C5: 100nF; C_Disc_D7.5mm_W4.4mm_P5.00mm
C6, C9: 100nF; C_0805_2012Metric
C7: 10uF 25V; C_1206_3216Metric
C8: 10nF; C_0805_2012Metric
D1: SMCJ58CA; D_SMC
D2: BAT54S; SOT-23
D3: BZX85C12; D_DO-41_SOD81_P10.16mm_Horizontal
D4: CHOP_ACTIVE; LED_D3.0mm
D5: ES3D; D_SMC
F1: BF1 58V MIDI 50A (142.7010.5502); Fuse_MIDI_BF1-58V_50A_BoltDown_2xM6_P30mm
J2: TERM; PinHeader_1x02_P2.54mm_Vertical
J3: PWR M1; AMASS_XT30PW-F_1x02_P2.50mm_Horizontal
J4: CANA; JST_GH_SM02B-GHS-TB_1x02-1MP_P1.25mm_Horizontal
J5: PWR M2; AMASS_XT30PW-F_1x02_P2.50mm_Horizontal
J6: CANB; JST_GH_SM02B-GHS-TB_1x02-1MP_P1.25mm_Horizontal
J7: PWR M3; AMASS_XT30PW-F_1x02_P2.50mm_Horizontal
J9: PWR M4; AMASS_XT30PW-F_1x02_P2.50mm_Horizontal
J11: PWR M5; AMASS_XT30PW-F_1x02_P2.50mm_Horizontal
J13: PWR M6; AMASS_XT30PW-F_1x02_P2.50mm_Horizontal
J15: TERM2; PinHeader_1x02_P2.54mm_Vertical
J16: BATT_SENSE; PinHeader_1x02_P2.54mm_Vertical
J17: DUMP_RESISTOR; AMASS_XT30PW-F_1x02_P2.50mm_Horizontal
J19: THERMAL_SW; PinHeader_1x02_P2.54mm_Vertical
Q1: MMBT3906; SOT-23
Q2: IRFB4110; TO-220-3_Vertical
R1, R5: 120R; R_Axial_DIN0207_L6.3mm_D2.5mm_P10.16mm_Horizontal
R2, R6, R13, R16, R17, R20: 10K; R_0805_2012Metric
R3: 1K; R_Axial_DIN0207_L6.3mm_D2.5mm_P10.16mm_Horizontal
R7, R10: 4.7K; R_0805_2012Metric
R8: 1K 3W; R_Axial_Power_L20.0mm_W6.4mm_P25.40mm
R9, R18: 100K; R_0805_2012Metric
R11: 5.1K; R_0805_2012Metric
R12: 1K; R_0805_2012Metric
R14: 1M; R_0805_2012Metric
R15: 100; R_0805_2012Metric
R19: 33K; R_0805_2012Metric
SW1: SW_SPDT; SW_Slide_SPDT_Straight_CK_OS102011MS2Q
U1: Teensy4.1; Teensy41
U2, U4: SN65HVD230; SOIC-8_3.9x4.9mm_P1.27mm
U3: TL431LP; TO-92_Inline
XT90PWRIN1: Conn_01x02_Pin; AMASS_XT90PW-M_1x02_P10.90mm_Horizontal

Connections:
+3.3V: C6.2, C9.2, D2.2 (K), R20.2, U1.15 (3V3), U1.46 (3V3), U1.51 (3V3), U2.3 (VCC), U4.3 (VCC)
+12V_CHOP: C7.1, D3.1 (K), Q1.2 (C), R8.2, R10.2
+48V: C1.1, C2.1, C3.1, C4.1, D1.2 (A2), D5.1 (K), F1.2, J3.1, J5.1, J7.1, J9.1, J11.1, J13.1, J17.1, R2.1, R8.1, R9.1
/CAN3_RX: U1.22 (30_CRX3), U4.4 (R)
/CAN3_TX: U1.23 (31_CTX3), U4.1 (D)
/CANH_A: J2.1, J4.2, U2.7 (CANH)
/CANH_B: J6.2, J15.1
/CANH_B: U4.7 (CANH)
/CANL_A: J4.1, R1.2, U2.6 (CANL)
/CANL_B: J6.1, R5.2, U4.6 (CANL)
/CAN_RX: U1.45 (23_A9_CRX1_MCLK1), U2.4 (R)
/CAN_TX: U1.44 (22_A8_CTX1), U2.1 (D)
/DUMP_OVERTEMP: J19.1, R20.1, U1.3 (1_TX1_CTX2_MISO1)
/GATE_DRV: Q1.3 (E), R13.1, R14.1, R15.1
/TRIP: R10.1, R12.1, R18.1, U3.3 (K)
/TRIP_3V3: R18.2, R19.1, U1.2 (0_RX1_CRX2_CS1)
/VBUS_IN: F1.1, XT90PWRIN1.1
/VMON: D2.3 (COM), R7.1, U1.36 (14_A0_TX3_SPDIF_OUT)
/VSENSE: C8.1, R9.2, R14.2, SW1.2 (B), U3.1 (REF)
GND: C1.2, C2.2, C3.2, C4.2, C5.2, C6.1, C7.2, C8.2, C9.1, D1.1 (A1), D2.1 (A), D3.2 (A), D4.1 (K), J3.2, J5.2, J7.2, J9.2, J11.2, J13.2, J16.2, J19.2, Q2.3 (S), R3.2, R11.2, R16.1, R17.2, R19.2, U1.1 (GND), U1.34 (GND), U1.47 (GND), U1.52 (GND), U1.58 (GND), U1.59 (GND), U1.64 (GND), U2.2 (GND), U2.8 (Rs), U3.2 (A), U4.2 (GND), U4.8 (Rs), XT90PWRIN1.2
unnamed: D4.2 (A), R13.2
unnamed: D5.2 (A), J17.2, Q2.2 (D)
unnamed: J2.2, R1.1
unnamed: J15.2, R5.1
unnamed: C5.1, J16.1, R3.1, R6.2, R7.2
unnamed: Q1.1 (B), R12.2
unnamed: Q2.1 (G), R15.2, R16.2
unnamed: R2.2, R6.1
unnamed: R11.1, SW1.1 (A)
unnamed: R17.1, SW1.3 (C)

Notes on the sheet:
Actuators
Power Input
Shunt regulator / brake chopper. 48V mode: trip 51.4V, release ~50.4V. 24V mode: trip 27.4V, release ~26.2V. Never move mode switch while powered. Dump: Arcol HS100 4R7 100W on heatsink via J17 + KSD9700-70 NC thermal switch. Supply OVP must exceed trip voltage.
Battery Monitor

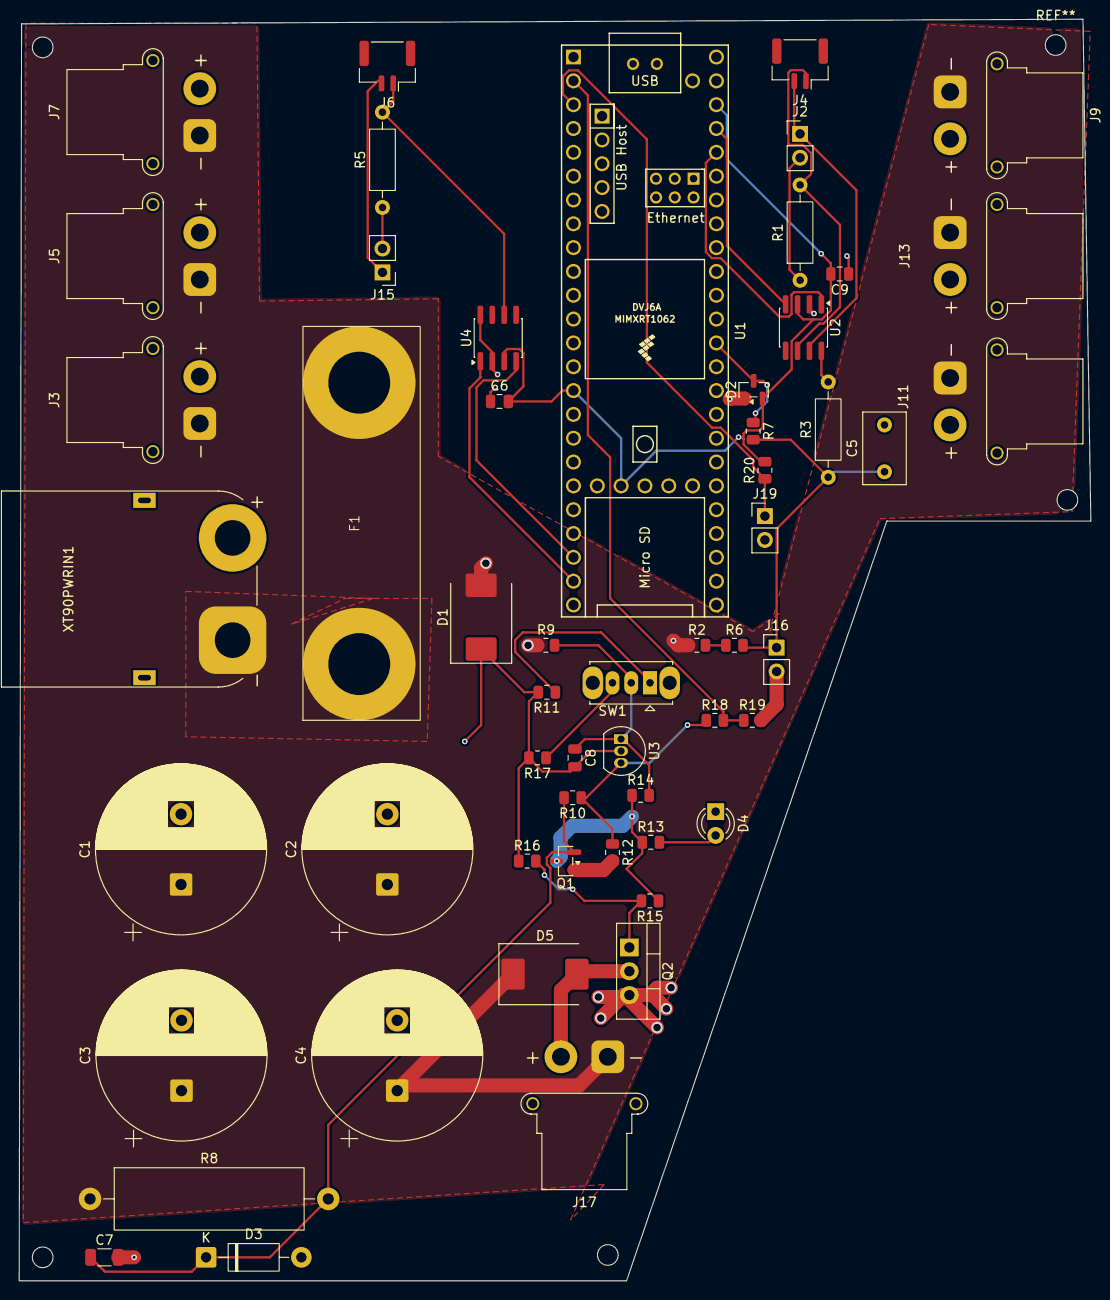
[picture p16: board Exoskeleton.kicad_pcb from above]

Board: 4 copper layers, 114.2 x 134.5 mm, 55 parts (0 on the bottom side), 29 nets.

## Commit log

2026-07-15 Fix pcb folder tracked as submodule
    [Exoskeleton.csv, Exoskeleton.kicad_pcb, Exoskeleton.kicad_sch]
2026-07-23 Added mounting holes and removed excess CAN trace
    [Exoskeleton.csv, Exoskeleton.kicad_pcb, bom.csv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]
2026-07-23 Files for ordering.
    [Exoskeleton-JLCPCB Assembly Order (1).xls]
2026-07-23 DIGI KEY ORDER
    [2026-07-23T120924.xlsx]
2026-08-15 Write structured README for the exoskeleton project
    Replace the image-only README with an Overview/Features/Repository
    layout/BOM section covering the Pitt Exo lower-limb exoskeleton
    (SolidWorks mechanical assembly + KiCad power distribution board).
2026-08-20 Add Strap Mount part to July 2026 exo assembly
    [Strap Mount.SLDPRT]
2026-10-03 Add exoskeleton walking simulation
    MuJoCo model of the human + hip/knee exo, the human and exo controllers,
    the stepping environment, PPO training scripts and the trained walking
    policy. Exo meshes are exported from the July 2026 SolidWorks assembly.
    [00_Left_Waist_07032026.obj, 00_Left_Waist_07032026_hull00.obj, 01_Middle_Waist_Part_07032026.obj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]
